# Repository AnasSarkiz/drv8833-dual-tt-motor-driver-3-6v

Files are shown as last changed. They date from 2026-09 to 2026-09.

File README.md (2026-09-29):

# DRV8833 dual TT motor driver, 3–6 V — routed prototype

[Public PCB](https://tscircuit.com/AnasSarkiz/drv8833-dual-tt-motor-driver-3-6v#pcb) · [GitHub repository](https://github.com/AnasSarkiz/drv8833-dual-tt-motor-driver-3-6v)

**Alpha.8:** the bottom silkscreen now reads “For evaluation only; not FCC approved for resale.” [Preview, fabrication artwork and checks](artifacts/silkscreen-review/README.md). Use the [updated fabrication ZIP](artifacts/silkscreen-review/jlc-fabrication-bottom-label.zip) for this label; the older alpha.6 order packet does not include it. [Publication status](PUBLICATION.md).

Revision A; package 0.1.0-alpha.8. **Routing is complete; physical qualification for fabrication and sale is still pending.** Native netlist and placement checks, full schema validation and fresh native routing checks pass. See [VALIDATION.md](VALIDATION.md) for evidence and remaining classified warnings.

Alpha.7 improves the four schematic sheets with nearby chip functions/ratings and connector labels. Electrical connections, PCB geometry and the alpha.6 prototype manufacturing packet are unchanged. [Schematic design review and previews](SCHEMATIC_REVIEW.md).

**Prototype order packet:** [Layout/export fixes completed; final quote and manufacturer preview remain](ORDER_READINESS.md). [Current stock for five boards](artifacts/order-release/STOCK.md).

A four-layer driver module for two brushed TT motors, controlled by an external host. The [reference TT motor](https://www.adafruit.com/product/3777) mounts to the chassis separately. This PCB is **75 × 60 × 1.6 mm**, with four **3.2 mm non-plated M3 holes on 65 × 50 mm centers** and 7 mm hardware keepouts. It is a generic module with a custom mounting pattern; compatibility with a particular chassis is not claimed. [Dimensioned mounting template](artifacts/routed/mounting-template.svg).

Minimum via drill **0.30 mm**, minimum via pad **0.45 mm**. The final board has 72 trace records, 60 through vias and ground pours on top, inner1 and bottom. Inner1 also carries signal routes. The four vias under U1 are thermal vias connected to ground, not mounting posts. [Routing details and layer previews](ROUTING_REVIEW.md).

The design has 47 purchased parts, 23 imported part types, five LEDs, seven bare test pads, separate A/B shunts and an NTC divider. The input target is **3–6 V at J1 including supply tolerance**. Nominal current chopping is about 1.33 A/channel; neither this nor the 1 A/channel continuous objective is a verified board rating. Hot-path voltage loss, regenerative spikes and thermal performance need bench testing. F1 is a non-resettable 3 A fuse; diagnose the fault before replacement. [Electrical review](DESIGN_REVIEW.md).

**SW1 — HOLD TO DISABLE:** hold the button to disable both motor outputs and let the motors coast. Release returns control to the host and can restart motion. It does not disconnect board power. [Button design and operating details](BUTTON_REVIEW.md).

## Connector pinout

All pin numbers are component pin numbers. Header geometry and assembly orientation remain under review.

| Connector | Pin 1 | Pin 2 | Pin 3 |
|---|---|---|---|
| J1 input | VIN | GND | — |
| J2 motor A | AOUT1 | AOUT2 | — |
| J3 motor B | BOUT1 | BOUT2 | — |
| J4 host power/enable | VIO input | GND | ENABLE / nSLEEP |
| J5 channel A | AIN1 | AIN2 | GND |
| J6 channel B | BIN1 | BIN2 | GND |
| J7 diagnostics | FAULT_N | TEMP | GND |

VIO is supplied by the host: match 3.3 V logic with 3.3 V VIO, or 5 V logic with 5 V VIO. It is not a power output. Mixed-voltage configurations are not approved. Pull-downs hold all commands and ENABLE low with disconnected high-impedance host pins. The host must drive ENABLE low before initialization, set commands to coast, then enable and wait at least 1 ms before PWM. Use command inputs for speed PWM, not nSLEEP. Both inputs low request coast, unequal inputs request drive, both high request brake; direction depends on motor wiring. All timing and sequencing require prototype confirmation.

LED1 indicates protected VM; LED2 VIO; LED3/4 unequal A/B commands (they can light while the driver sleeps); LED5 asserted fault. No LED measures rotation. TEMP measures local board temperature, not motor winding or silicon junction temperature. Its revised 56 kΩ/10 kΩ divider gives TEMP≈0.1515×VIO at 25°C; it is not an automatic cutoff. TP1/2 expose raw switching sense nodes, not calibrated ADC current telemetry. TP3 is GND; TP4 VM; TP5 VIO; TP6 FAULT_N; TP7 TEMP.

## Reproduce and inspect

Run `bun install --frozen-lockfile`, `bun run format:check`, `bun run typecheck`, `bun run build`, then `bun test`. `bun run render` regenerates the layer and schematic previews. Build validates the real generated output and checks physical routing; it does not patch Circuit JSON or suppress errors. The saved routes are editable native TSX route paths with validated component anchors.

Three unpublished, source-patched toolchain packages are included in `vendor/`, with exact upstream bases, regression tests and patches in [references/toolchain-fixes](references/toolchain-fixes/README.md). See [TOOLCHAIN.md](TOOLCHAIN.md).

- [BOM](BOM.md), [imports](IMPORTS.md), [placement](PLACEMENT_REVIEW.md) and [mechanical dimensions](MECHANICAL.md)
- [Validation](VALIDATION.md), [routing status](ROUTING_GATE.md) and [tool limitations](ISSUES.md)
- [Assembly review](ASSEMBLY_PLAN.md) and [physical test plan](TEST_PLAN.md)
- [Working reference comparison](REFERENCE_BOARD_REVIEW.md)
- [Public repository and registry receipts](PUBLICATION.md)

Earlier `artifacts/pre-route/` files are historical and are superseded by `artifacts/routed/`. No manufacturing order has been placed.

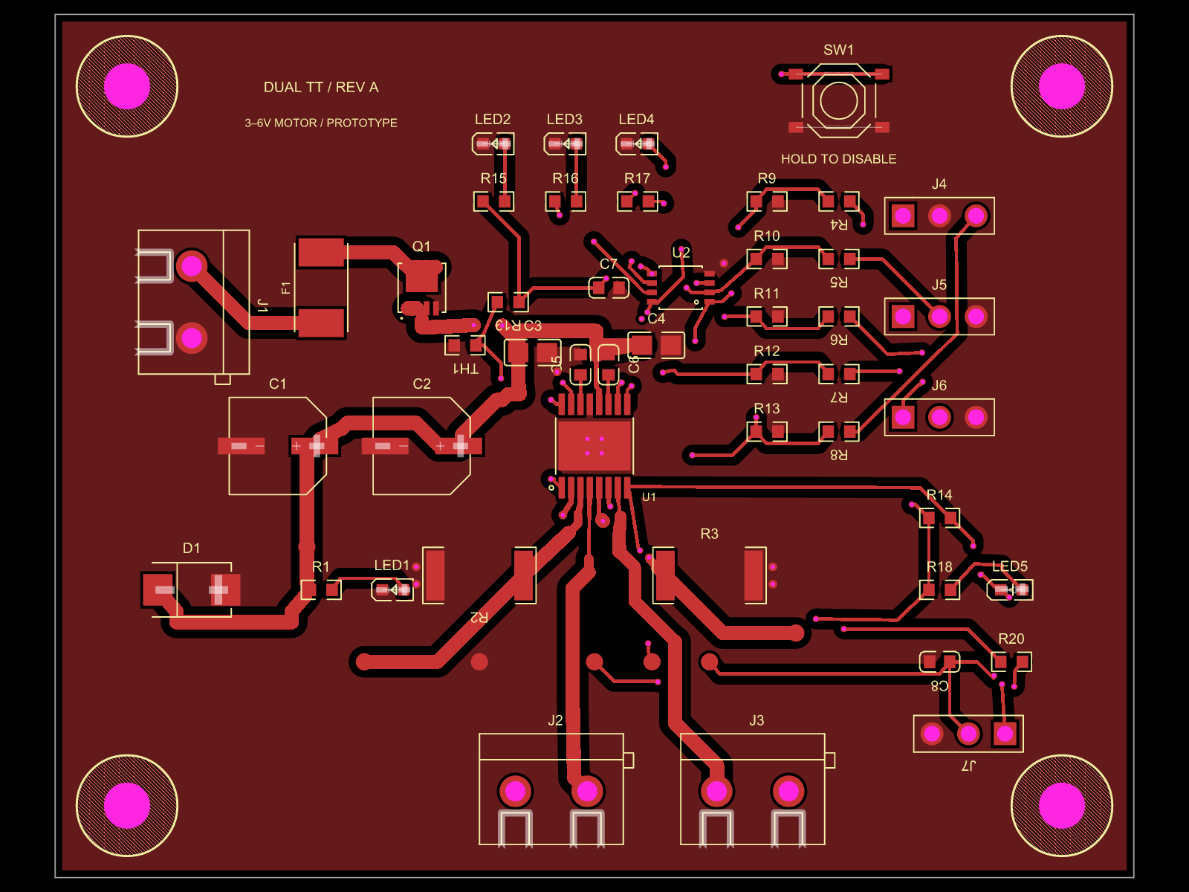
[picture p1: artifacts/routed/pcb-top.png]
Routed top layer


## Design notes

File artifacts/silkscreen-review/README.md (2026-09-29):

# Bottom evaluation label — alpha.8

The bottom silkscreen reads:

> For evaluation only;  
> not FCC approved for resale.

Both lines use 1.8 mm lettering, centered at (0, 25) mm and (0, 22.5) mm. The exported stroke width is 0.162 mm. Visual inspection confirms clearance from through-hole pads, vias and mounting hardware zones. Bottom text is mirrored in the top-down layer drawing so it reads correctly when the physical board is viewed from underneath.

- [Bottom layer preview](../routed/pcb-bottom.png)
- [Fabrication artwork ZIP with the label](jlc-fabrication-bottom-label.zip)
- [Native combined export](dual-tt-bottom-label-gerbers.zip)
- [Artwork comparison and generated label records](verification.json)

Netlist: zero errors/warnings. Placement DRC: zero errors/warnings; the existing C7 orientation advisory remains. Format, TypeScript, build, schema, mechanical and physical-connectivity checks pass. All 27 existing tests / 1,139 assertions pass. No new tests or check exemptions were added for this silkscreen-only change.

All non-silkscreen PCB records and electrical connectivity records are identical to the previous build. After ignoring export timestamps and resolving aperture-number renumbering, comparison against the alpha.6 manufacturing artwork finds exactly one changed file: `B_SilkScreen.gbr`. Copper, drills, outline, top silkscreen, solder mask and paste are unchanged.

The fabrication ZIP contains only native Gerber/drill files. J1–J7 still require manual assembly; retain the existing separate SMT assembly files and manufacturing notes. The native combined export's all-component pick-and-place file still has the documented J4–J7 orientation warnings.

See [publication status](../../PUBLICATION.md) for GitHub and tscircuit verification. The older alpha.6 order packet remains a historical export without the new label. No stock refresh, production order or regulatory approval is implied.

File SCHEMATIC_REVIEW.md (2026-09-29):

# Schematic design review — alpha.7

Reviewed 29 September 2026. The four sheets now include native `<schematictext>` notes beside every chip: U1, U2 and the chip-style Q1 symbol. Labels also identify all connectors, the disable button and the temperature measurement.

| Part | Nearby explanation |
|---|---|
| U1 DRV8833 | Two brushed-DC motor bridges; IC VM range 2.7–10.8 V, board input target 3–6 V, nominal 1.33 A/channel current chopping; continuous current requires thermal testing |
| U2 SN74LVC2G86 | Dual XOR for command LEDs; IC VCC range 1.65–5.5 V, board VIO 3.3/5 V; indication measures commands rather than rotation |
| Q1 SI7655ADN | P-channel reverse-polarity protection, −20 V VDS rating and source/drain/exposed-pad connections |

Ratings were checked against the [TI DRV8833 datasheet](https://www.ti.com/lit/ds/symlink/drv8833.pdf), [TI SN74LVC2G86 datasheet](https://www.ti.com/lit/ds/symlink/sn74lvc2g86.pdf) and [Vishay SI7655ADN datasheet](https://www.vishay.com/docs/62909/si7655adn.pdf). IC limits are distinct from the board's intended supply and unqualified continuous-current target.

Host headers and input networks use separate schematic sections to replace obstructing ground wires with labeled connections. Diagnostic test pads are likewise separated from J7. Notes have consistent font size and line spacing, remain inside their sheets and were visually checked against wires, symbols and labels in all four regenerated previews. Native schematic-placement checks report no collision or overlap findings. Remaining box-padding and orientation suggestions are non-blocking style heuristics, retained without suppression.

The build, full schema guard, native netlist, mechanical checks and native routing checks pass. Placement DRC reports zero errors and warnings, with the existing advisory C7 orientation suggestion. All 27 board tests pass with the same 1,139 assertions; the independent drill and pad rejection cases now run separately, each retaining the default runner deadline and full validation.

All 1,000 PCB records, 54 CAD records and electrical component/port/net/trace records exactly match alpha.6. Every file in the alpha.6 order-release directory is unchanged. [Comparison evidence](artifacts/schematic-review/unchanged-hardware.json) and [check logs](artifacts/schematic-review/logs/). The schematic update adds no hardware or manufacturing qualification.

## Rendered sheets

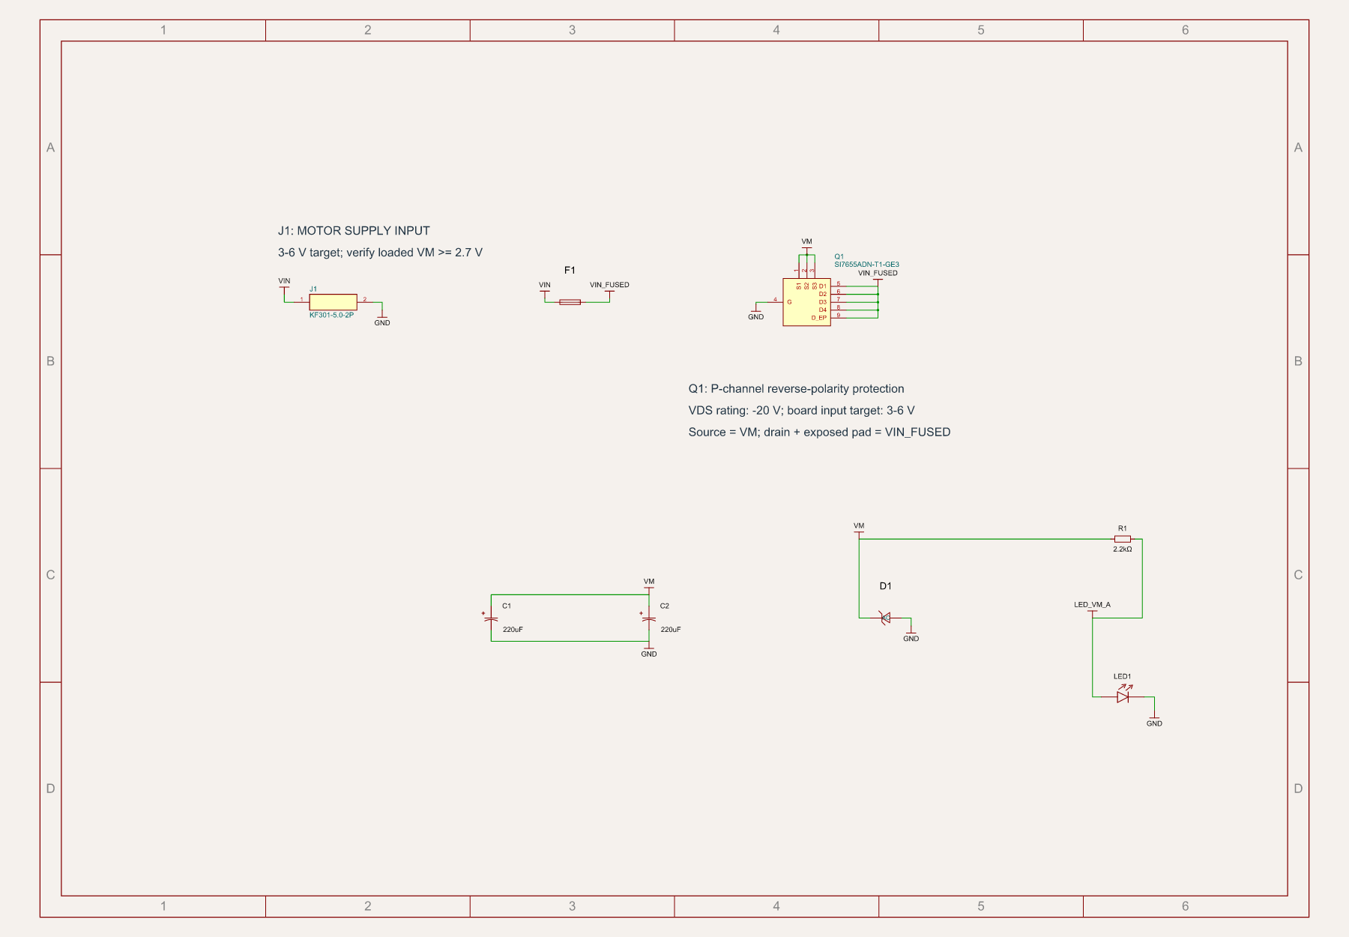
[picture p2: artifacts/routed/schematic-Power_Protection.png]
Power and protection


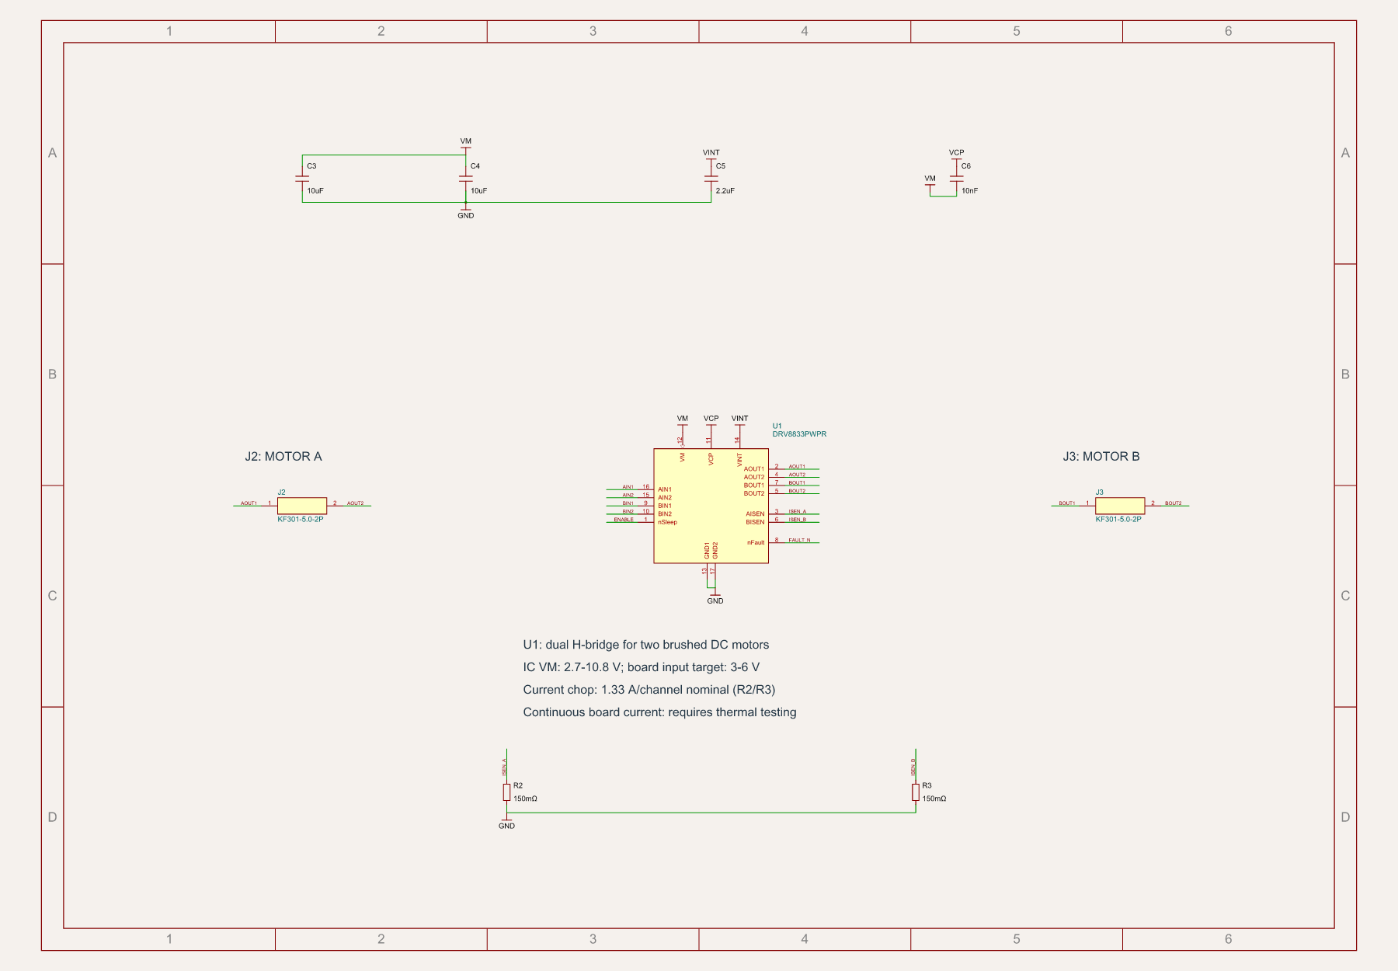
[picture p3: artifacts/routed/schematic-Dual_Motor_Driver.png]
Dual motor driver


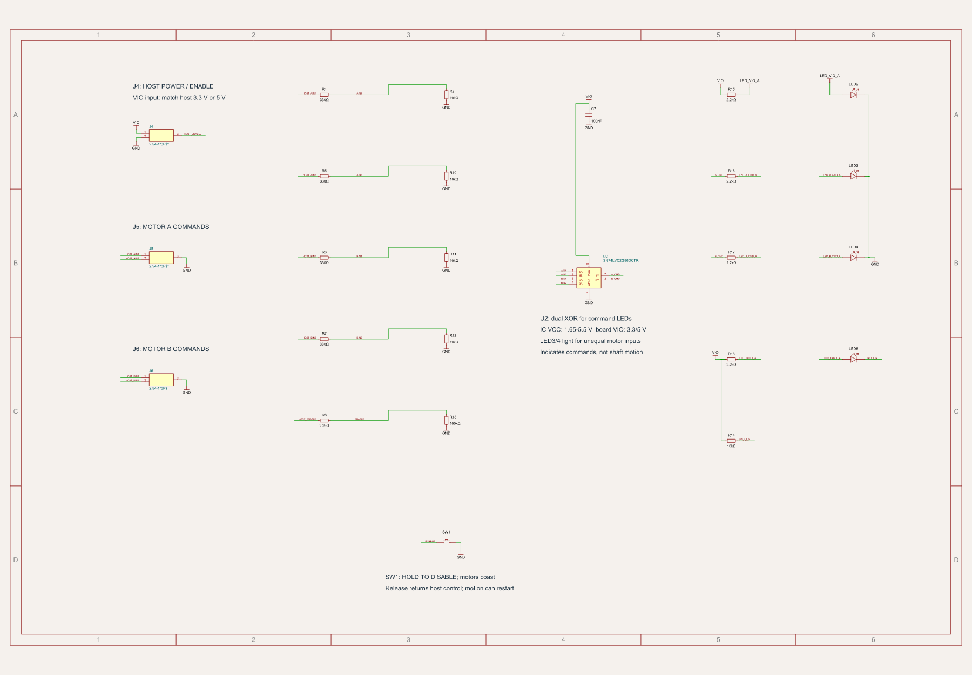
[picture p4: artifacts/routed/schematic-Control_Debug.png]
Control and debug


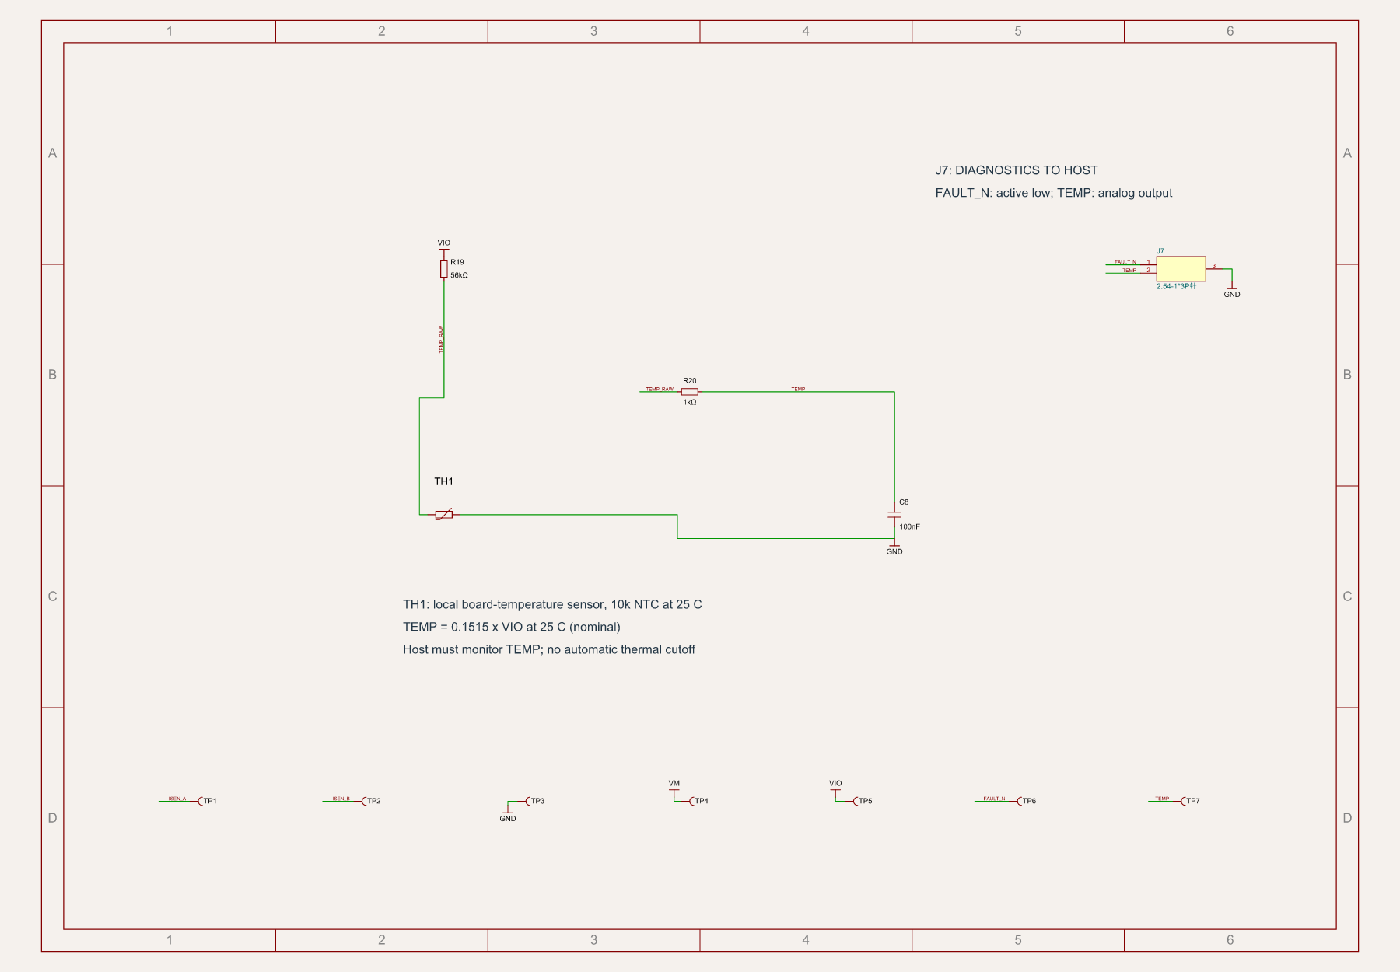
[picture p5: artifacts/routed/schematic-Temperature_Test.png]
Temperature and test access


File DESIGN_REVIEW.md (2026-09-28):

# Electrical design review — incomplete

Analysis only; no physical measurements or circuit simulation. This file records both calculations and blocking decisions. The alpha.3 prototype is now routed and passes automated routing checks. The physical rating and manufacturing qualification items below remain open; routing does not resolve them.

## Power architecture

J1 VIN → F1 fuse → Q1 drain, Q1 source → VM. The P-channel gate is at GND; its body diode starts the protected rail in the correct direction. VM feeds U1, two bulk capacitors, local ceramic bypass, the TVS candidate and VM LED. This arrangement does not block returned regenerative current when Q1 is on. U1 GND and exposed pad are separate from the AISEN/BISEN nodes, which each connect to GND only through their own 0.15 ohm shunt.

The store-product target remains **3.0–6.0 V at J1, including supply tolerance**, for two small TT motors. The user's adjustable regulated supply is test equipment, not a restriction on the product. Battery packs and regulated adapters must be assessed by their actual voltage range and ability to accept returned motor energy. Nominal pack labels alone do not establish compatibility; no specific battery pack, USB source or adapter is approved yet.

Q1 is now Vishay **Si7655ADN-T1-GE3, C222495**. Its 9 mΩ maximum at VGS=-2.5 V and 25°C replaces AO3401A's 85 mΩ. Its gate limit is ±12 V and drain rating 20 V. Physical pins 1/2/3 are source (VM), 4 gate (GND), 5/6/7/8 drain (VIN_FUSED); imported pad 9 is the same exposed drain metal. The datasheet bottom view was visually checked. The exact imported land pattern and assembly process still need completion. [Vishay datasheet](https://www.vishay.com/docs/62909/si7655adn.pdf).

F1 is now Littelfuse **0453003.MR, C178991**, a **non-resettable 3 A fuse**. This replaces the PTC; a blown fuse requires fault diagnosis and replacement. Its nominal cold resistance is 22.7 mΩ, not a guaranteed hot maximum. At 25°C use the manufacturer's 75% continuous-current derating: 2.25 A; ambient rerating applies additionally. This is input fault protection, not the per-channel motor limiter. The datasheet allows up to 5 s opening at twice rated current, so it does not guarantee semiconductor survival during every fault. Source fault current and fuse/TVS coordination remain to be closed. [Littelfuse 451/453 datasheet](https://www.littelfuse.com/assetdocs/fuse-451-and-453-datasheet?assetguid=533cd5cc-956c-4243-867f-6ab5a62f6ba1).

At 2 A shared input, Q1 plus F1 contribute approximately 2×(0.009+0.0227)=**0.0634 V** and 0.127 W, versus the prior optimistic 0.29 V. This combines a room-temperature MOSFET maximum with a fuse nominal: it is an estimate, not a system guarantee. A provisional hot-path design budget of Q1≤20 mΩ, F1≤50 mΩ and contacts/copper≤30 mΩ totals 0.20 V at 2 A, leaving VM≥2.8 V for 3.0 V measured at J1. These are acceptance targets to verify, not manufacturer-guaranteed bounds. Supply sag must not pull J1 below 3 V. Reliable simultaneous starts at minimum input remain unverified.

D1 is now **Littelfuse SMBJ6.0A, C83270**, replacing the unverified MSKSEMI candidate. The manufacturer series sheet specifies 6.0 V standoff, 6.67–7.37 V breakdown at 10 mA, and 10.3 V maximum clamp at 58.3 A for its stated pulse condition. Reverse leakage is up to **800 µA**, not the supplier-description number. The 0.046%/°C column is a breakdown temperature coefficient. Do not treat 600 W pulse capability as continuous braking power or scale the clamp by the breakdown coefficient and call it guaranteed. The 10.3 V value leaves only 1.5 V to U1's 11.8 V absolute limit; hot clamping, wiring/layout overshoot and repetitive energy must be budgeted. [Manufacturer SMBJ series sheet, supplier-hosted](https://datasheet.lcsc.com/datasheet/pdf/4ab84a227fae39f9eac85241b8264ead.pdf).

Two 220 µF capacitors give 440 µF nominal and 352 µF at -20%. Ignoring losses, returned energy of 1 mJ from 6 V raises VM to 6.46 V; 10 mJ raises it to 9.64 V. These are examples, not measured TT-motor energies. Required braking/reversal energy, pulse repetition, bulk ESR/ripple/lifetime and transient clamp temperature remain open. **The regenerative-energy solution is not approved.** Q1 conducts returned current when on; it is not a reverse-current blocker. Do not assume a bench supply or power bank can absorb this energy.

## Driver pin audit

Compared with [TI DRV8833 PWP pin table](https://www.ti.com/lit/ds/symlink/drv8833.pdf):

| Pad | Imported signal | Intended net |
|---|---|---|
| 1 | nSleep | ENABLE |
| 2 | AOUT1 | AOUT1 |
| 3 | AISEN | ISEN_A |
| 4 | AOUT2 | AOUT2 |
| 5 | BOUT2 | BOUT2 |
| 6 | BISEN | ISEN_B |
| 7 | BOUT1 | BOUT1 |
| 8 | nFault | FAULT_N |
| 9 | BIN1 | BIN1 |
| 10 | BIN2 | BIN2 |
| 11 | VCP | VCP |
| 12 | VM | VM |
| 13 | GND1 | GND |
| 14 | VINT | VINT |
| 15 | AIN2 | AIN2 |
| 16 | AIN1 | AIN1 |
| 17 | GND2 / exposed pad | GND |

C6 is VCP-to-VM, not VCP-to-GND. C5 bypasses VINT, with no external VINT load. C3/C4 provide 20 uF nominal VM ceramic capacitance; exact DC-bias/temperature curves must establish the effective minimum. Driver PWM strategy, fault recovery and wake timing still need a consolidated worst-case review.

## Current limit and thermal targets

The [TI DRV8833 datasheet](https://www.ti.com/lit/ds/symlink/drv8833.pdf) specifies a 160/200/240 mV current-trip threshold at the table's stated conditions. With 0.15 Ω ±1%, the calculated range is **1.056–1.616 A** at those conditions; nominal 1.333 A. Including a ±600 ppm/°C shunt TCR over a 75°C change expands the resistor scenario to **1.011–1.692 A**. That is not a guaranteed all-temperature IC limit. Switching blanking and motor inductance can permit additional overshoot. Nominal shunt dissipation is 0.267 W; the upper resistor/threshold scenario is about 0.406 W. Shunt pulse/derating and a lower-TCR alternative remain under review.

At the datasheet's 85°C, 5 V resistance condition, a bridge's combined maximum on-resistance is 0.600 Ω: two channels at 1 A imply about 1.2 W conduction loss. At the 2.7 V condition the estimate is 1.3 W. These extrapolations exclude switching and other losses. An engineering junction target of 125°C at 40°C ambient and 1.3 W requires effective thermal resistance below 65°C/W before those extra losses. The datasheet fixture is not this board. Copper spreading, filled thermal vias, enclosure airflow and actual motor duty need verification. **1 A/channel continuous remains a target, not a product rating.** FAULT_N is not a stall detector; the host needs a blocked-motor timeout.

## Host interface and indicators

R4–R7 use **330 Ω ±1% C23138** and 10 kΩ pull-downs. Commands allowing 33 µA driver plus 5 µA XOR leakage give approximately 2.697 V at host VOH=2.8 V. Alpha.6 uses **R8=2.2 kΩ C4190 / R13=100 kΩ C25803** for ENABLE, giving at least 2.710 V with the stated 13 µA input current and worst resistor tolerances. SW1 pulls ENABLE low while held; R8 limits pressed host current to 2.411 mA at 5.25 V. Require a GPIO that can source at least 2.5 mA. These calculations use datasheet input-current test conditions; they are not a universal host guarantee. For a 5 V host, require matching VIO and verify loaded VOH against U2's 0.7×VIO requirement; a 4.4 V host-high target provides useful margin at VIO≤5.25 V. Input edge rate and loading still need oscilloscope qualification. See [button review](BUTTON_REVIEW.md) for contact topology and restart behavior.

Use VIO from the same host rail: 3.3 V or 5 V, with no arbitrary mixed-voltage modes. The [SN74LVC2G86](https://www.ti.com/lit/ds/symlink/sn74lvc2g86.pdf) allows inputs to 5.5 V and supports partial power-down; its input edge-rate limits still apply. Series resistance is not a complete connector ESD solution.

Worst preliminary FAULT loading at 5.25 V is about 2.11 mA from LED5 and its 10 kΩ pull-up, leaving margin below the 5 mA characterized sink condition. Limit additional external loading and verify host low threshold against 0.5 V. LED1 indicates VM, LED2 VIO, LED3/4 unequal channel commands, LED5 asserted fault. Command LEDs can light while asleep; none measures rotation.

## Temperature interface correction

The [Murata NCP18XH103F03RB specification](https://www.murata.com/products/productdetail?partno=NCP18XH103F03RB) lists 0.1 mA maximum measuring current at 25°C. The original equal-10 kΩ divider exceeded this. **R19 is now 56 kΩ ±1% C23206.** Even at VIO=5.25 V and R19=-1%, divider current stays below 94.7 µA as NTC resistance approaches zero. At 25°C nominal TEMP/VIO is 10/(56+10)=0.151515: 0.500 V at 3.3 V or 0.758 V at 5 V. Estimated self-heating at the upper rail is about 0.065°C using the typical dissipation constant; the actual board environment changes it.

Use R_NTC=56000×TEMP/(VIO−TEMP), assuming negligible ADC loading and a ratiometric reference. TEMP is a raw board-temperature signal, not an automatic cutoff or motor/junction reading. The full manufacturer R/T table and final accuracy budget remain open; the 25/50 beta value must not be used as a guaranteed full-range conversion.

R20=1 kΩ and C8=100 nF give roughly 0.95 ms at 25°C and a nominal cold limit of 5.7 ms. Allow at least 35 ms initial settling, subject to capacitor tolerance. The host must use a high-impedance ADC and suitable acquisition time; its input must accept the complete 0–VIO range. Open/short sensor readings approach rail endpoints and require host fault handling.

## Power states and motor commands

TI explicitly allows digital inputs before VM. U2 supports powered-off inputs within its specified range. This resolves the earlier blanket prohibition on host-first power-up; it does not authorize every hot-plug or backfeed configuration.

| VM | Host VIO | Host commands | Design behavior / condition |
|---|---|---|---|
| absent | absent | high impedance | No driven motor operation |
| present | absent | high impedance | External pulls request sleep/coast; leakage/default state requires prototype confirmation |
| absent | present | valid 0–VIO levels | Host-first sequencing allowed by the IC specifications; keep ENABLE low |
| present | present | ENABLE low | Sleep requested |
| present | present | ENABLE high | Wait at least 1 ms after waking; set motor commands deliberately |
| returns after interruption | present | ENABLE already high | Motor may restart immediately; host must handle supply recovery and hold sleep during initialization |
| either | VIO powered independently of an unpowered host | FAULT/TEMP connected | Unsupported: those outputs can backfeed the host |
| either | changing | hot plug / long leads | Connector bounce, transients and ESD not qualified |

Drive PWM on the command inputs, not nSLEEP. Both low request coast, unequal inputs drive, both high request brake. A brake command and rapid reversal require the unresolved energy review above. Before initialization or mode changes, deassert ENABLE and choose a controlled restart sequence. VIO is an input, never a board power output.

## Remaining pre-routing decisions

Close the bus-energy budget and fault-source assumptions, capacitor bias/ripple review, shunt pulse/TCR choice, exact footprints and assembly process, connector access in 3D, and external-port ESD/interface limits. Software schema defects are tracked separately in ISSUES.md. All physical tests remain NOT RUN. The generic 75 × 60 mm chassis module and mounting pattern are accepted; no specific chassis is required to continue. MCU, crystal, USB, firmware flashing, radio, charger and encoder are NOT APPLICABLE to this external-controller design.

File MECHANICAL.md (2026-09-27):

# Chassis mounting — revision A prototype

The user selected a standalone chassis-mounted module and has not selected a chassis. The PCB uses ordinary M3 hardware with a **custom 65 × 50 mm rectangular hole pattern**. This is a practical module size, not a standardized pattern or a claim of direct fit to every TT chassis. Motors attach to their chassis or brackets separately; short wires connect them to J2/J3.

| Feature | Design dimension |
|---|---|
| PCB outline | 75 × 60 mm |
| Thickness / stack | 1.6 mm / four layers |
| Mounting holes | Four 3.2 mm non-plated holes, for M3 screws |
| Hole centers | 65 × 50 mm; each center 5 mm from two adjacent edges |
| Coordinates about board center | H1 (−32.5, +25), H2 (+32.5, +25), H3 (−32.5, −25), H4 (+32.5, −25) mm |
| Hardware reserve | 7 mm diameter at every hole, copper keepout on all four layers |
| Proposed spacers | Four M3 insulating standoffs, 10 mm tall; check actual solder-tail clearance |
| Via minima | 0.30 mm drill / 0.45 mm copper pad; these are unrelated to mounting-hole size |

[Mounting template](artifacts/routed/mounting-template.svg) is drawn in physical millimeters. Print at 100% and check the 50 mm scale with a ruler. It is a mechanical review aid, not a PCB fabrication package. The canonical dimensions are in `references/mechanical.json`; source holes, keepouts and template use that file.

Use a flat chassis deck or adapter that accepts this hole rectangle, with room beyond the board for wiring. Do not drill a purchased chassis until you check its motor, wheel, battery and structural clearances. Use insulating standoffs over metal; washers and screw heads must fit within the reserved 7 mm diameter. Clearance to connector housings, mated plugs, wire bends and the screwdriver requires a physical or verified 3D check. Vertical headers need access from above; screw terminals also need top tool access. Fastener lengths depend on the actual chassis thickness and standoff thread depth and are not selected yet.

The real generated output is checked for board size, all four holes/keepouts and all 53 component/test-pad courtyard envelopes by `scripts/check-mechanical.ts`. Each component courtyard must clear every hardware reserve by at least 0.5 mm. Both this geometric check and full Circuit JSON schema validation pass for the routed prototype.

Research supports the mounting arrangement: [Adafruit's TT chassis](https://www.adafruit.com/product/3796) places the TT motors on its side walls and provides holes/slots for controller boards on the deck. Its [dimension drawing](https://cdn-shop.adafruit.com/product-files/3796/3796_diagram_2.jpg) does not define a universal controller-board pattern. That discontinued chassis was used as a reference only; this PCB is not advertised as matching its existing holes. Actual chassis fit and enclosure heights remain unverified until a chassis is selected.

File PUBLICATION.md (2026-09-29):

# Public routed release

## Alpha.8 — bottom evaluation label

**Alpha.8 is published to both public repositories.** The bottom silkscreen now reads “For evaluation only; not FCC approved for resale.” [Bottom preview and updated fabrication ZIP](artifacts/silkscreen-review/README.md).

| Destination | Verified result |
|---|---|
| GitHub source | `d1f7bbf01a7ee00ec65604b4830edd94331d7d5b` pushed to `main` |
| [GitHub CI](https://github.com/AnasSarkiz/drv8833-dual-tt-motor-driver-3-6v/actions/runs/36605200165) | PASS: frozen install, format, TypeScript, build and 27 tests / 1,139 assertions |
| [tscircuit PCB](https://tscircuit.com/AnasSarkiz/drv8833-dual-tt-motor-driver-3-6v#pcb) | Latest release `0.1.0-alpha.8-routed`; release ID `20e4c3da-a9a2-4ae0-bc2e-cdc5a9c807a3` |
| Upload verification | 388 files uploaded; all 256 non-dotfile source/toolchain/review hashes match |
| Cloud build | Completed successfully; 1,921 schema-valid records, zero error records and zero native routing findings |
| Cloud comparison | All 1,002 PCB, 468 schematic and 54 CAD records exactly match local output; electrical connections also match |
| Bottom label | Both lines present on `bottom`, with 1.8 mm font size |

[Machine-readable publication receipt](artifacts/silkscreen-review/publication.json). Only bottom silkscreen artwork changes relative to the alpha.6 manufacturing export after normalizing timestamps and aperture numbers. Copper, drills, mask, paste and top silkscreen are unchanged. The older alpha.6 order packet does not contain the new label; use the separate updated fabrication ZIP linked above.

The registry's aggregate display status remains `pending` despite successful completion of its custom build and verified generated output. This GitHub-only receipt records the results; the registry snapshot contains the preceding publication-status document. The online editor's separate saved-routing issue remains tracked in [tscircuit/core#4197](https://github.com/tscircuit/core/issues/4197); this silkscreen update does not resolve it.

## Alpha.7 — schematic review receipt

Both repositories are public. **Alpha.7 adds the reviewed schematic notes and labels and passes local, GitHub CI and tscircuit cloud checks.** Its PCB, electrical connections and alpha.6 prototype manufacturing packet are unchanged.

| Destination | Verified result |
|---|---|
| [GitHub](https://github.com/AnasSarkiz/drv8833-dual-tt-motor-driver-3-6v) | Public; alpha.7 source, previews and review evidence pushed |
| [GitHub CI](https://github.com/AnasSarkiz/drv8833-dual-tt-motor-driver-3-6v/actions/runs/36557758551) | PASS: frozen install, format, TypeScript, build and all 27 tests / 1,139 assertions |
| [tscircuit schematic](https://tscircuit.com/AnasSarkiz/drv8833-dual-tt-motor-driver-3-6v#schematic) | Public; latest release `0.1.0-alpha.7-routed`; new notes confirmed in the live viewer |
| Release ID | `9af54a06-8175-491e-a563-65f439ab72b8` |
| Published source commit | `74fee42fa5bdbf5f3e427e5dbdb20cfa620682b3` |
| Upload verification | 377 files uploaded; all 246 non-dotfile source, toolchain, manufacturing and review hashes match through the public API |
| Cloud build | Completed without error; all 1,919 records pass schema and routing-contract validation; native routing checks: 0 findings |
| Cloud comparison | All 1,000 PCB records and 468 schematic records exactly match local output, including all 26 new note lines |
| Manufacturing comparison | All 53 alpha.6 order-release files remain byte-identical |

See [schematic review](SCHEMATIC_REVIEW.md) for the four rendered sheets and chip-rating sources. The PCB still has 72 traces, 60 vias, four pour polygons, 110 top paste apertures and no bottom paste. Notes identify U1, U2, Q1, connectors, the disable button and temperature measurement without changing physical circuitry.

The local output includes 47 supplier-lookup network warnings that are absent from the cloud output. These report inability to connect, not missing imported footprints; all PCB, CAD, electrical and schematic records match exactly. The only other local/cloud difference is the source filesystem metadata hash. Native placement and symbol style advisories remain documented without suppression. Registry aggregate display status remains pending and its separate thumbnail URL is absent despite successful code generation and the functioning schematic viewer.

The 247-entry manifest includes one dot-prefixed GitHub workflow excluded by registry upload rules. All other hashes match. The registry snapshot contains the preceding publication receipt; this later GitHub-only receipt and [publication.json](artifacts/routed/publication.json) record alpha.7's remote results. Publication receipts and their upload/CI logs are excluded from the manifest.

The unchanged [prototype order packet](artifacts/order-release/dual-tt-prototype-order-packet.zip) remains subject to [order readiness](ORDER_READINESS.md), final manufacturer review and stock reservation. The stock evidence is dated 28 September 2026 and was not refreshed for this schematic-only revision. Physical motor, supply-spike, button and thermal tests remain necessary before a store release. No order has been placed.

The repositories are published separately. Automatic linking previously returned `403 repository_not_accessible` from the tscircuit GitHub app; no broader app permissions were granted.

## Repository rename

On 2026-09-28, both repositories were renamed to `drv8833-dual-tt-motor-driver-3-6v`. Existing public visibility, repository/package IDs, history and previous releases were preserved.

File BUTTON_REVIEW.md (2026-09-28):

# Motor-disable button — alpha.6

SW1 is a normally-open momentary tactile button, labeled **HOLD TO DISABLE**. Holding it pulls the DRV8833 ENABLE/nSLEEP input low and disables both H-bridges. Motors coast; the board remains powered. Releasing it returns control to the external host and can restart the motors after the driver's wake delay. This is a local operating control, not a latching stop, active brake, power disconnect or emergency-stop circuit. No new firmware is required for its basic function.

Comparable DRV8833 carriers expose sleep/enable control, as in the [Adafruit pinout guide](https://learn.adafruit.com/adafruit-drv8833-dc-stepper-motor-driver-breakout-board/pinouts) and [Pololu carrier](https://www.pololu.com/product/2130). A button is an optional convenience; these references do not establish a universal button convention. The chosen momentary disable function uses the [TI nSLEEP behavior](https://www.ti.com/lit/ds/symlink/drv8833.pdf), sections 7.3.4 and 7.4.

## Electrical and mechanical review

- **SW1: XKB TS-1187A-B-A-B, JLC C318884**, Basic, top SMT, 5.1 × 5.1 × 1.5 mm body; 50 mA / 12 V DC contact rating. The [manufacturer drawing](references/TS-1187A-B-A-B.pdf) was visually reviewed. A–B (pins 1–2) and C–D (pins 3–4) are permanent pairs; pressing connects the two pairs. A/B connect to ENABLE, C/D to GND. The native pushbutton model explicitly includes these pairs.
- The supplier footprint has 1.00 × 0.75 mm pads at X=±3.00 mm, Y=±1.849882 mm. The drawing's suggested land pattern gives X=±3.00 mm, Y=±1.875 mm; the 0.025118 mm Y difference is inside its general ±0.1 mm tolerance. The imported body courtyard is retained. Parts-engine pin-1 matching verifies the supplied CPL orientation; the final assembly preview must confirm the contact-row axis, since a 90° error would bridge ENABLE to ground.
- **R8 changes from 330 Ω to 2.2 kΩ (C4190)**. With a 5.25 V host and −1% resistance, pressing draws at most 2.411 mA from HOST_ENABLE and dissipates about 12.66 mW in R8 (100 mW part). Require a host GPIO that tolerates this source current. At the switch's specified 100 mΩ maximum contact resistance, ENABLE is below 0.25 mV, well under the 0.5 V input-low limit.
- **R13 changes from 10 kΩ to 100 kΩ (C25803)**. At host VOH=2.8 V, R8=+1%, R13=−1%, and the datasheet's stated 13 µA nSLEEP current, ENABLE is at least 2.710 V, above the 2.5 V threshold. This is a calculation at the specified input-current conditions, not a universal host guarantee. R13 and the driver's internal pull-down retain the disconnected-host sleep default. The four motor-command inputs retain 330 Ω / 10 kΩ networks.
- SW1 center is (17,24) mm on top, away from the corner mounting keepout and host connectors. Its two added ENABLE paths use 0.25 mm copper and two 0.30/0.45 mm vias. All previous saved power and signal paths remain unchanged. Ground contacts join the checked top pour. Four-layer, 75 × 60 mm board size and mounting pattern are unchanged.

## Verification and use

Native netlist and placement DRC: zero errors/warnings. Full schema, build, mechanical and native routing checks pass. The existing advisory C7 rotation suggestion remains. All 26 board tests / 1,139 assertions pass, including released/pressed switch contact topology, GPIO current budget, enable-high margin, ground continuity and strict supplier orientation. All four copper layers and the control schematic were visually inspected. Gerber-mode shorts at 40 px/mm reports no shorts. Final exports contain 40 top SMT placements, seven manual connectors, 110 top stencil apertures and no bottom paste.

Bench checks: with motors initially disconnected, measure ENABLE released/pressed at both supported host voltages; verify the host can source the pressed current. Test with wheels lifted: hold SW1 to remove drive, then confirm expected restart behavior on release. Verify wake timing, contact bounce and supply transients before normal operation. Use the external controller or a separate suitable power disconnect when a maintained stop is required. The existing motor/load/thermal test plan still applies.

Import and validation evidence: [button review artifacts](artifacts/button-review). Fresh component quantities: [five-board stock check](artifacts/order-release/STOCK.md). The final manufacturer preview, inventory reservation and physical tests remain separate.

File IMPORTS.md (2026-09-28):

# Import audit

23 selected part types imported with `tsci import C-number --jlcpcb --use-exact-footprint`. No fabricated packages. Original generated modules remain unchanged. The initial imports have logs in `artifacts/pre-route/import-results.json`; revision imports have separate logs in `artifacts/pre-route/logs/`. Unused original imports are retained for provenance and are not BOM rows. The original import hashes remain in `artifacts/pre-route/import-hashes.json`; the current imports are included in `artifacts/routed/hashes.json`.

An import is not an independent geometry review. DRV8833 pin labels match the PWP table. The design uses the TI-derived land pattern in lib/driver-footprint.tsx; see U1_FOOTPRINT.md. Its four ground thermal vias are listed in `references/thermal-structures.json`, including exact positions and sizes. The routed revision adds signal/power and ground-stitching vias; see ROUTING_REVIEW.md. Raw import geometry is unchanged.

Raw non-IC imports use generic chips. lib/parts.tsx supplies native electrical kinds, explicit connector entry directions and reference text while preserving the raw import files. U1 and F1 use separately reviewed manufacturer-derived footprints; see U1_FOOTPRINT.md and ASSEMBLY_PLAN.md. D1 was re-imported as Littelfuse C83270; R4–R7 use C23138 and R19 uses C23206. Q1 now uses Vishay C222495 and F1 uses non-resettable Littelfuse C178991. Import logs are retained. See ISSUES.md.

Alpha.6 adds C318884 (native pushbutton) and C25803 (100 kΩ resistor), imported with the same exact-footprint command. R8 reuses C4190 (2.2 kΩ). Raw imports remain unchanged; button contact pairs are declared by the board circuit using the reviewed manufacturer drawing. New logs and identity records are in `artifacts/button-review/`.

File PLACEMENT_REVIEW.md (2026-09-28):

# Placement review — routed prototype

The outline is 75 × 60 × 1.6 mm with four copper layers. Four 3.2 mm NPTH holes form a 65 × 50 mm rectangle, with 7 mm hardware keepouts on all layers. This is the accepted generic chassis-module arrangement, not a specific chassis fit claim.

All 47 purchased components are on top, together with seven bare test pads. There are 54 checked courtyards and 64 PCB-component records (including ten explicitly authored thermal/ground vias). Native placement DRC reports zero errors and warnings; the CLI’s separate C7 orientation suggestion is advisory. Every courtyard is inside the outline and clears each hardware reserve by at least 0.5 mm; J7 is the closest at 0.732 mm beyond the hardware zone. See `artifacts/order-release/logs/build.log`.

J1 faces the left edge; motor connectors J2/J3 face the bottom. The shunts are adjacent to the driver, with nearby ground stitches. C3/C4 and the sense/VM test-pad positions were adjusted to permit clean routing. U2's 2D courtyard is clear. Four layer previews are in `artifacts/routed/`.

The four U1 holes are conductive thermal vias, not mounting posts. Their 0.3048 mm drills / 0.6096 mm pads exceed the requested minima and now connect to GND copper. Six further ground stitches support the shunts, C3 and logic ground; all routes and pours are checked together for physical continuity.

Connector mating envelopes, tool access, standoff height, imported 3D model alignment and physical chassis fit remain unverified. Routing and 2D checks do not establish thermal performance or assembly readiness. See ASSEMBLY_PLAN.md and TEST_PLAN.md.

Alpha.5 capacitor positions: C3 (−4.3, 6.5), C4 (4.3, 7), C5 (−0.975, 5.65), C6 (0.975, 5.65) mm. C5/C6 rotate 90°. Both small-capacitor pin routes are now 2.05 mm without vias. All affected routes and courtyards were rechecked.

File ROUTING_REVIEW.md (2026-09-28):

# Routed revision A review

Routing is complete and passes fresh native routing checks with zero findings. All 32 non-GND nets use 71 saved reviewed native route paths; a short C3 ground connection makes 72 trace records. GND continuity is established through the checked ground pours, thermal vias and six added stitches.

The saved routes in `lib/saved-routing.ts` are canonical, editable route paths referenced by real component pin selectors. They originated from native capacity-autorouter 0.0.938, pipeline9, with additional routing margins. Alpha.5 locally revises U1 current return, bypass placement and affected neighboring paths. Alpha.6 adds two ENABLE route paths and two vias for SW1; the prior 69 saved paths are unchanged. They are consumed by the supported `autoroutingphase` API, which checks anchors, physical layers and endpoint coverage. Moving a component requires updating its affected saved paths. No Circuit JSON is injected or repaired after generation.

| Copper feature | Final geometry |
|---|---|
| Stack | Four layers, 1.6 mm board |
| Ground copper | Top (two polygons), inner1 and bottom (one polygon each) |
| Inner1 | Ground pour with some signal routes; not an exclusive or uninterrupted plane |
| Signal/power vias | 50 total: 49 at 0.30/0.45 mm; AOUT1 transition at 0.30/0.60 mm |
| Added ground stitches | Six, drill 0.30 mm / pad 0.60 mm |
| Original U1 thermal vias | Four, drill 0.3048 mm / pad 0.6096 mm |
| Board minimum via rule | Drill 0.30 mm / pad 0.45 mm |
| Trace widths | 0.25 mm minimum; power nets request 1 mm with narrower pad escapes |
| Clearance rules | Trace/pad 0.15 mm; via/pad 0.20 mm; board edge 0.50 mm |
| Ground pour | 0.20 mm clearance, 0.60 mm trace margin; solid connections |

Ground stitching is beside both shunts, C3 and the logic supply. U1's four thermal vias remain centered under its exposed ground pad. Ground copper is included in the physical continuity check; negative tests prove that removing the pours creates failures. Solid pour connections may need additional soldering heat, and U1's filled/capped via process still needs assembler confirmation.

## Power copper measurements

These are total planar route lengths, summed across branches; via barrel lengths are excluded. A width range includes narrow fanout sections as well as wider tracks. It does not establish a continuous-current or transient rating.

| Net | Total routed length (mm) | Width range (mm) |
|---|---:|---:|
| VIN | 10.638 | 1.000 |
| VIN_FUSED | 11.329 | 0.405–1.000 |
| VM | 77.280 | 0.325–1.000 |
| AOUT1 | 22.472 | 0.400–1.000 |
| AOUT2 | 21.943 | 0.250–1.000 |
| BOUT1 | 24.059 | 0.250–1.000 |
| BOUT2 | 26.557 | 0.325–1.000 |
| ISEN_A | 21.298 | 0.400–1.000 |
| ISEN_B | 18.679 | 0.300–1.000 |

[Complete measured geometry](artifacts/routed/routing-metrics.json) is generated by `scripts/record-routing-review.py`. The native trace-length report is also retained, but its net summary includes logical branch/centroid distances; the table above measures actual wire segments. Narrow escape sections, via plating, copper weight and current sharing need thermal/current qualification on a prototype. No 1 A continuous rating is asserted.

## Layer previews

- [Top](artifacts/routed/pcb-top.png)
- [Inner1](artifacts/routed/pcb-inner1.png)
- [Inner2](artifacts/routed/pcb-inner2.png)
- [Bottom](artifacts/routed/pcb-bottom.png)
- [Mounting template](artifacts/routed/mounting-template.svg)

All four layers were visually inspected, including the four hardware keepouts. Native build/schema/routing checks and independent Gerber-mode shorts checks pass. See VALIDATION.md for exact evidence. Physical assembly, temperature, stall behavior, supply transients and chassis fit remain untested.

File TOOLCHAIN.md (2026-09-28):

# Toolchain

Pinned on 2026-09-27. Bun 1.3.9; TypeScript 5.9.3; Biome 2.5.14. `bun.lock` is the dependency lockfile. Registry automatic dependency upgrades are disabled.

| Package | Version |
|---|---|
| tscircuit | 0.0.2646 |
| @tscircuit/cli | 0.1.2167 |
| @tscircuit/core | 0.0.1993-dualtt.6, local archive |
| @tscircuit/circuit-json-util | 0.0.116-dualtt.1, local archive |
| circuit-json | 0.0.506-dualtt.1, local archive |
| @tscircuit/props | 0.0.666 |
| @tscircuit/checks | 0.0.221 |
| @tscircuit/capacity-autorouter | 0.0.938 |

The three active local archives in `vendor/` are unpublished builds from canonical upstream source, not npm releases. Exact base commits, complete patches, tests and logs are in [references/toolchain-fixes](references/toolchain-fixes/README.md). Fixes cover position metadata serialization, real plated-hole IDs, optional board-artwork ownership, physical layer anchors on saved routes at plated connectors, and preservation of local trace widths beside saved vias. Electrical and copper-clearance checks remain unchanged.

The schema suite passed 397 tests / 1,899 assertions. Focused core regression tests, TypeScript and package/declaration builds passed; six saved-route regression cases passed 39 assertions. The complete upstream core suite was not run. `scripts/rebuild-toolchain-fixes.py` documents a clean rebuild from the pinned upstream sources; that complete helper has not been executed from scratch. No installed dependency or generated board JSON is patched at runtime, and the user's separate core checkout was not changed.

`index.circuit.tsx` is the canonical board entrypoint. `lib/saved-routing.ts` holds native-generated route paths consumed through the supported `autoroutingphase` API. All 32 non-GND nets are explicitly assigned to this phase; GND is joined by pours and authored stitching. The default rerender validates route anchors and recreates the copper. `routeRemaining={false}` prevents an extra autorouting pass; it does not disable full physical-connectivity or routing checks.

Commands used for final validation: `tsci check netlist`, `tsci check placement`, `tsci check pin_specification`, `tsci check source`, `tsci check trace-length net.VM`, `tsci build`, native `runAllRoutingChecks`, full schema parsing, project tests, mechanical checks and Gerber-mode shorts. `bun run render` converts unmodified generated Circuit JSON to images.

The earlier partial investigation in `references/core-schema-fix/` is historical. The complete fixes above supersede its unresolved status. No upstream issue, PR or npm publication was made.

The registry runtime preloads dependency symlinks and does not provide Python. The mechanical gate therefore also has a native Bun/TypeScript implementation, equivalent to the original Python check. The cloud build command performs a forced frozen-lockfile install before the complete project build, so preloaded libraries cannot create a mixed dependency graph. No check is omitted.

Alpha.5 additionally removes automatic paste from THT pads, resolves two-terminal orientation with sub-micron imported coordinate rounding, invalidates old unknown-orientation cache entries, and supports outline keepouts in the current schema. No footprint coordinates, polarity or copper are changed by the orientation classifier. Six new/updated assembly regression cases pass; all 25 board tests pass. The utility library’s full run had 137 passes and one unrelated renderer-snapshot mismatch. The core artwork snapshot also differs in one path’s rendering. Both mismatches were reproduced with the prior source and left unchanged; baseline evidence is in references/toolchain-fixes. Type/declaration builds and the changed-function tests pass. The rebuild helper is a source recipe; a complete fresh dependency rebuild has not been rerun.

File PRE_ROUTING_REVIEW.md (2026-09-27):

# Work required before routing

> Historical review from before routing. Current routing and validation status is documented in ROUTING_REVIEW.md and VALIDATION.md. Earlier routing holds/schema failures below describe that historical revision and are superseded.

Review date: 2026-09-27. The user wants a store product for common TT motors; the test bench's regulator does not define its sole power source. Target input remains 3–6 V at the connector including tolerance. Routing is disabled, with no routing approval requested for this incomplete revision.

The user's working RP2040 motor board is now a documented comparison in [REFERENCE_BOARD_REVIEW.md](REFERENCE_BOARD_REVIEW.md). Its delivered and latest designs differ; the comparison adds logical ground-connectivity regression coverage and an outside-pad thermal-via option for review. It does not change our hardware, supply target, or routing state.

## Completed in this revision

- Replaced Q1 with Vishay C222495 and F1 with Littelfuse C178991 to reduce power-path voltage loss. F1 is now a non-resettable fuse. Added actual physical pin-net regression coverage.
- Replaced D1 with documented Littelfuse SMBJ6.0A C83270 and audited the clamp/leakage data.
- Corrected R19 to 56 kΩ to meet the NTC measuring-current limit. Reduced host series resistors to 330 Ω for better high-level margin.
- Derived U1 lead, thermal-copper, mask and paste geometry from TI's drawing. Kept four documented thermal vias and established filled/capped via-in-pad as the proposed process.
- Added proper component wrappers, connector entry directions and pin attributes. Moved motor connectors/test pads and separated the TH1/R19 legends. Native 2D placement is clear.
- Expanded current-limit, thermal, host-first power, FAULT loading and TEMP calculations. No physical ratings are asserted.

## Open before a complete routing-approval package

| Item | Remaining work |
|---|---|
| Regenerative energy and source faults | Bound braking/reversal energy and repetition, hot TVS clamp plus layout overshoot, bulk ripple/ESR and fuse coordination. No universal supply compatibility claim. |
| Component qualification | Finish MLCC DC-bias, shunt TCR/pulse and exact passive/connector footprint review; resolve C25804 supplier stock. |
| Assembly and mechanical | Confirm via fill/cap and stencil process, Q1 paste/mask, connector drill fit, screwdriver/mating space and imported-model alignment. |
| Schematics | Add visible value/part annotations to the custom F1/D1/TH1 symbols and finish the page layout review. Remaining native orientation/padding findings are style suggestions, not electrical errors. |
| Software compatibility | Published core still emits schema-invalid offsets/IDs. Local reproductions and a tested partial generator fix exist; board-level silkscreen ownership additionally needs schema/API agreement. No generated output or validation has been patched. |

## Not a reason to delay independent work

A particular purchased chassis is not required: the accepted generic module is 75 × 60 mm with four 3.2 mm holes on 65 × 50 mm centers. It is not a universal chassis fit. Physical startup, overshoot, thermal, EMI and durability tests follow an approved routed prototype; they remain mandatory before selling a claimed performance rating. GitHub-to-registry automatic synchronization is separate from the PCB design.

The next review must present the updated BOM, all four schematics, assembly plan and placement together. Only explicit approval of that complete revision permits routing. See DESIGN_REVIEW.md, U1_FOOTPRINT.md, VALIDATION.md and ISSUES.md for evidence and limits.

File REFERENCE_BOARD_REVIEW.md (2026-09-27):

# Working reference board comparison

> Historical review from before routing. Current routing and validation status is documented in ROUTING_REVIEW.md and VALIDATION.md. Earlier routing holds/schema failures below describe that historical revision and are superseded.

Reviewed 2026-09-27 from the public tscircuit source, without rebuilding, routing, or modifying the reference board.

The user reports that an ordered board from [imrishabh18/rp2040-motor-controller](https://tscircuit.com/imrishabh18/rp2040-motor-controller) works. The exact ordered revision is uncertain. The latest release is **1.0.28**, dated September 26; its own README identifies **1.0.21** as the previously delivered iteration. That makes 1.0.21 a useful additional comparison, not a confirmed identification of the user's hardware. The user's report is recorded as physical-use evidence for their unit; no new measurements were performed here.

| Item | Delivered-iteration reference, v1.0.21 | Latest reference, v1.0.28 | Dual TT draft |
|---|---|---|---|
| Motor/control architecture | DRV8847, RP2040, NEMA 17 application | DRV8825, RP2040, STEP/DIR | DRV8833; two independent TT motors; external controller |
| Motor supply design | 9 V USB-PD | 20 V USB-PD | 3–6 V at the input terminal |
| Mechanical design | 42.30 × 42.32 mm motor cap; 31 mm mounting square | Same NEMA 17 outline | 75 × 60 mm chassis module; 65 × 50 mm mounting centers |
| Input protection/storage | 2 A PTC, SMBJ11CA, 220 µF bulk | PTC, reverse-current diode, SMBJ22CAQ, 22 µF/50 V bulk | Low-loss MOSFET, 3 A non-resettable fuse, SMBJ6.0A, 2 × 220 µF bulk |
| Temperature interface | TMP102 plus hardware sleep interlock and firmware | Same general interlock architecture | NTC output to host; no automatic cutoff |
| Minimum via sizes | 0.30 mm drill / 0.45 mm pad | 0.30 mm drill / 0.45 mm pad | Same minimums; four declared thermal vias are larger |

Version-specific sources: [v1.0.21](https://tscircuit.com/imrishabh18/rp2040-motor-controller?version=1.0.21), [v1.0.28](https://tscircuit.com/imrishabh18/rp2040-motor-controller?version=1.0.28). Retrieval identifiers and source hashes are in `references/rp2040-reference.json`.

## Changes and decisions from this comparison

- **Check ground by electrical connectivity.** Matching labels can hide separate ground networks across nested circuits. New tests traverse actual source-trace and internal-connection edges, check all 30 required ground returns, and keep power, outputs and sense inputs separate from ground. A deliberate exposed-pad disconnection with another net still named GND must be detected. These are logical checks; physical ground continuity remains a post-routing check.
- **Retain local bypassing and short high-current loops.** The reference uses local capacitors and wider motor/power copper. Apply that placement/routing principle with our driver's pin map and current/thermal calculations; copying its nominal widths would not establish our current rating. No copper was added in this review.
- **Review an outside-pad thermal-via option.** The latest reference places six tented thermal vias beyond its driver pad. This is a useful manufacturing alternative to evaluate for our U1. It does not yet replace our declared four-via, filled/capped option: the packages, heat paths, and paste requirements differ.
- **Keep the TT electrical and mechanical requirements.** The reference's NEMA 17 hole pattern and 9/20 V supply circuits do not establish fit or suitability for 3–6 V TT motors. TI specifies an 8.2 V minimum for DRV8825, so it cannot replace DRV8833 in this input range. See the [DRV8825](https://www.ti.com/lit/ds/symlink/drv8825.pdf) and [DRV8833](https://www.ti.com/lit/ds/symlink/drv8833.pdf) datasheets.
- **Keep temperature claims accurate.** The reference's autonomous temperature interlock is a separate function from our raw NTC output. Our host remains responsible for temperature handling; no interlock or onboard MCU was added.

The reference uses different pinned dependencies and board-specific patches. Its successful hardware use and automated checks are useful evidence, but do not resolve the independently reproduced schema failures in our current pinned toolchain. Power-spike, current, thermal, and assembly limits in PRE_ROUTING_REVIEW.md remain open. Routing remains disabled.

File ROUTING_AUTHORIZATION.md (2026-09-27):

# Routing authorization

On 2026-09-27 the user instructed: “conrue dont stop until we got the boaeed routd”. This explicitly authorizes routing and supersedes the earlier pre-route hold. The earlier review artifacts remain in `artifacts/pre-route` as historical evidence.

The board retains the 75 × 60 mm outline, four M3 holes, four copper layers, and minimum 0.30 mm via drill / 0.45 mm via pad. Schema validation, native electrical/placement/routing checks, thermal-via geometry and minimum-size checks remain mandatory. Completing routing does not qualify the prototype for sale or authorize a manufacturing order.

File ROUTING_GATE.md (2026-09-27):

# Routing status — complete

The user's explicit instruction to continue until routed supersedes the previous pre-route hold. See [ROUTING_AUTHORIZATION.md](ROUTING_AUTHORIZATION.md).

- [x] Native netlist and placement checks pass.
- [x] Full generated Circuit JSON schema validation passes.
- [x] Routing is enabled and all nets are physically connected, including GND through pours and stitching.
- [x] Fresh native routing checks report zero findings; no routing checks are disabled.
- [x] Minimum via drill 0.30 mm / pad 0.45 mm preserved.
- [x] Original four U1 thermal vias preserved and connected to ground.
- [x] Board outline, mounting holes, keepouts and 53 courtyards verified.
- [x] Regression tests protect connections, actual generated geometry and failure cases.
- [x] Four copper-layer previews generated and visually inspected.

This completes routing. Manufacturing and store qualification remain separate: exact assembly process, filled/capped thermal vias, selected chassis fit, temperature/current rating, low-voltage margin and regenerative-spike testing are still pending. No new routing permission is required. Public publication results are recorded in [PUBLICATION.md](PUBLICATION.md).

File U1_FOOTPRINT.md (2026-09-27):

# U1 footprint and thermal assembly review

Source: [TI DRV8833 datasheet](https://www.ti.com/lit/ds/symlink/drv8833.pdf), PWP0016C drawing 4224559/B, January 2019. `lib/driver-footprint.tsx` implements the land-pattern example rotated 90° so pin 1 is at bottom left. The supplier import is retained unchanged for provenance and its model/part identity; its original land pattern is not used.

| Feature | Implemented geometry |
|---|---|
| 16 lead pads | 0.45 × 1.50 mm; 0.65 mm pitch; rows at Y=±2.90 mm |
| Exposed-pad copper | 5.00 × 3.40 mm, covered by solder mask outside the opening |
| Exposed opening and paste | 2.31 × 2.46 mm centered; zero mask/paste expansion |
| Lead mask expansion | 0.05 mm per edge |
| Four thermal vias | 0.3048 mm drills, 0.6096 mm pads; exact positions in references/thermal-structures.json |

The two coincident pin-17 pads describe one electrical copper area and its smaller exposed center. The installed tool lacks per-side mask-margin implementation. This uses supported covered-pad and exposed-pad geometry; emitted copper/mask/paste records are tested. Export union/mask fidelity must be checked after routing approval before fabrication.

The four retained vias meet the requested 0.30 mm drill / 0.45 mm pad minima. They are a documented alternative to TI's illustrative via array; their thermal performance is not established by the drawing. They need **filled and copper-capped via-in-pad processing**, with a flat reflow surface. The TI stencil example is 0.125 mm thick. Confirm the exact process and paste coverage with the fabricator/assembler; no order or process acceptance exists yet.

These four holes are conductive thermal-via barrels, not mounting posts. The routed revision connects them and the exposed pad to GND pours; AISEN/BISEN remain separate until their shunts. Physical-connectivity and native routing checks pass. Mechanical fit of the imported 3D model and prototype thermal behavior remain unverified.

`tests/design-connectivity.test.ts` checks all 17 physical pin nets, lead pitch/position/size, thermal copper/opening and emitted paste. The source routing guard hashes this reviewed footprint and allows only the four listed thermal vias. This document is a geometry review, not assembly approval.

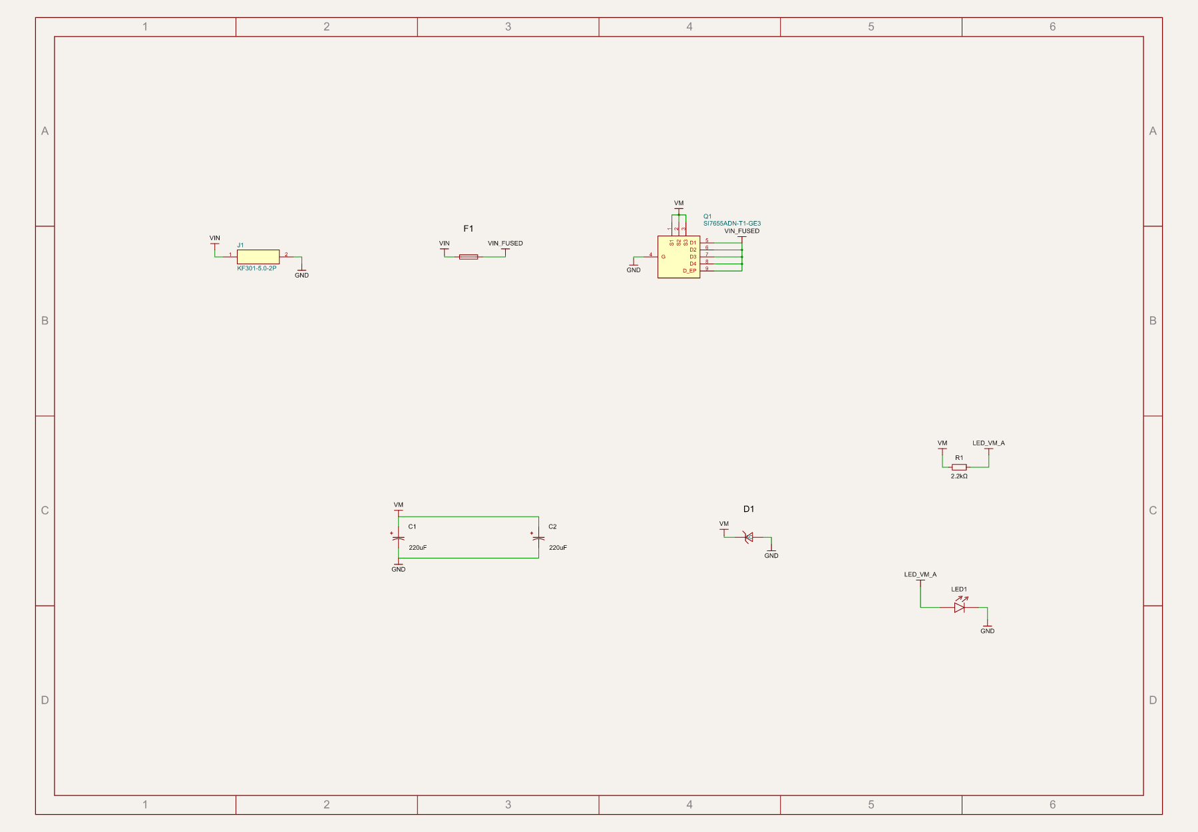
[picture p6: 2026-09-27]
artifacts/pre-route/schematic-Power_Protection.png

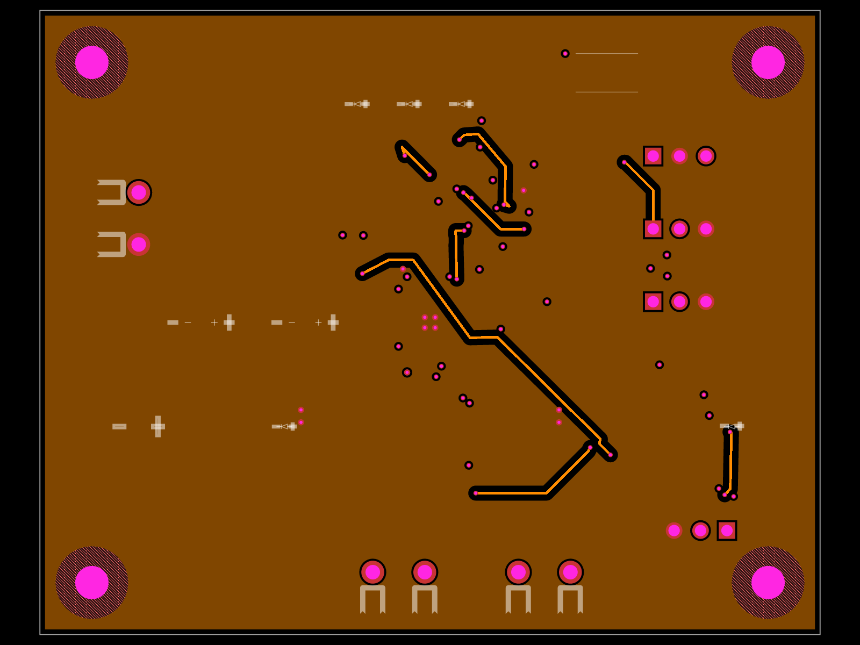
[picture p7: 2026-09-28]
artifacts/routed/pcb-inner1.png

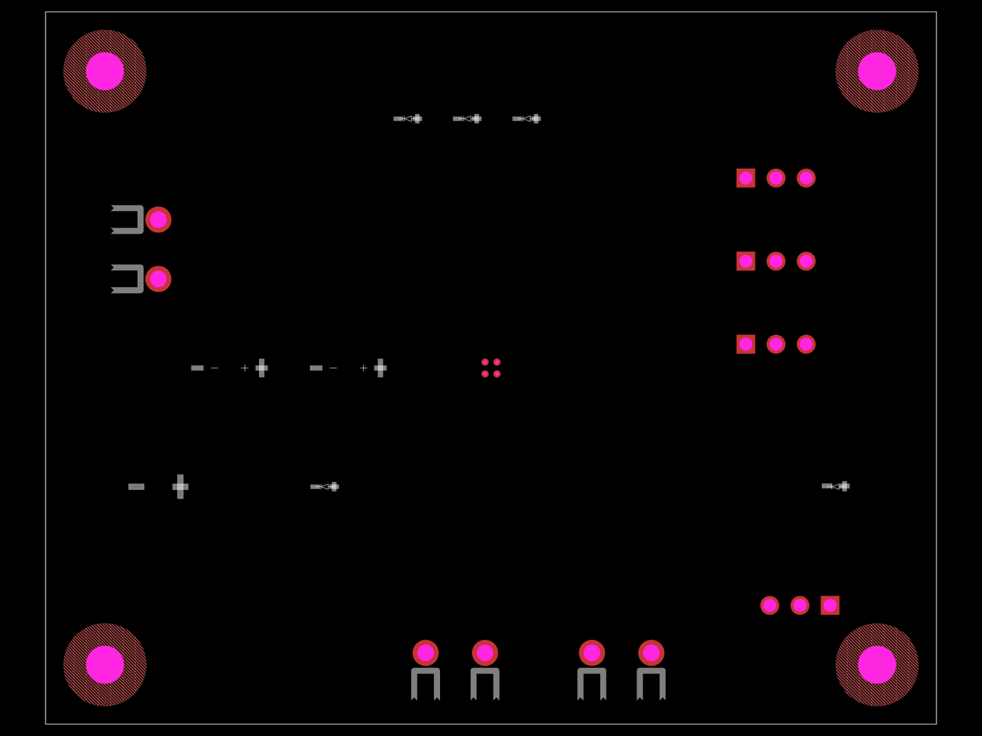
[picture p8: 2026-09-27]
artifacts/pre-route/pcb-bottom-unrouted.png

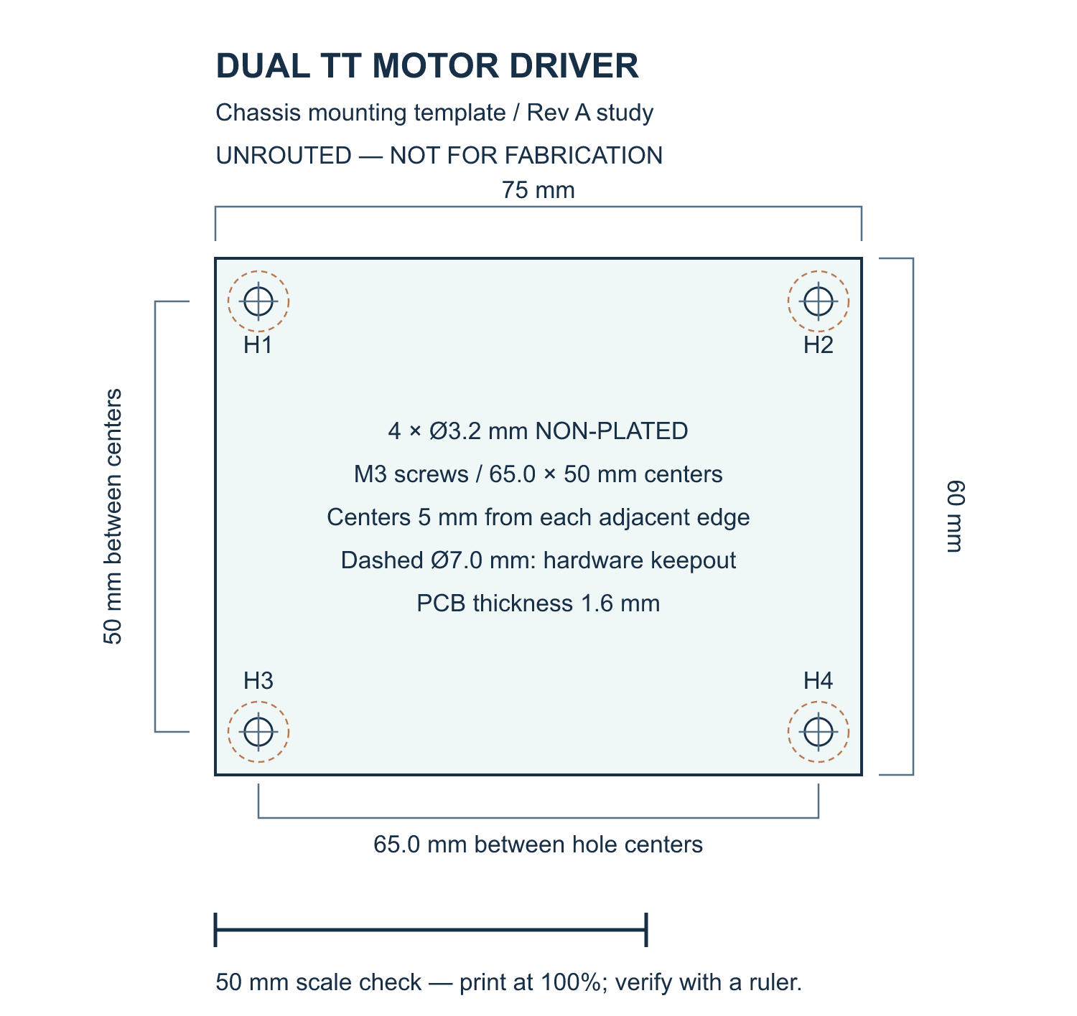
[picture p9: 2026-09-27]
artifacts/routed/mounting-template.png

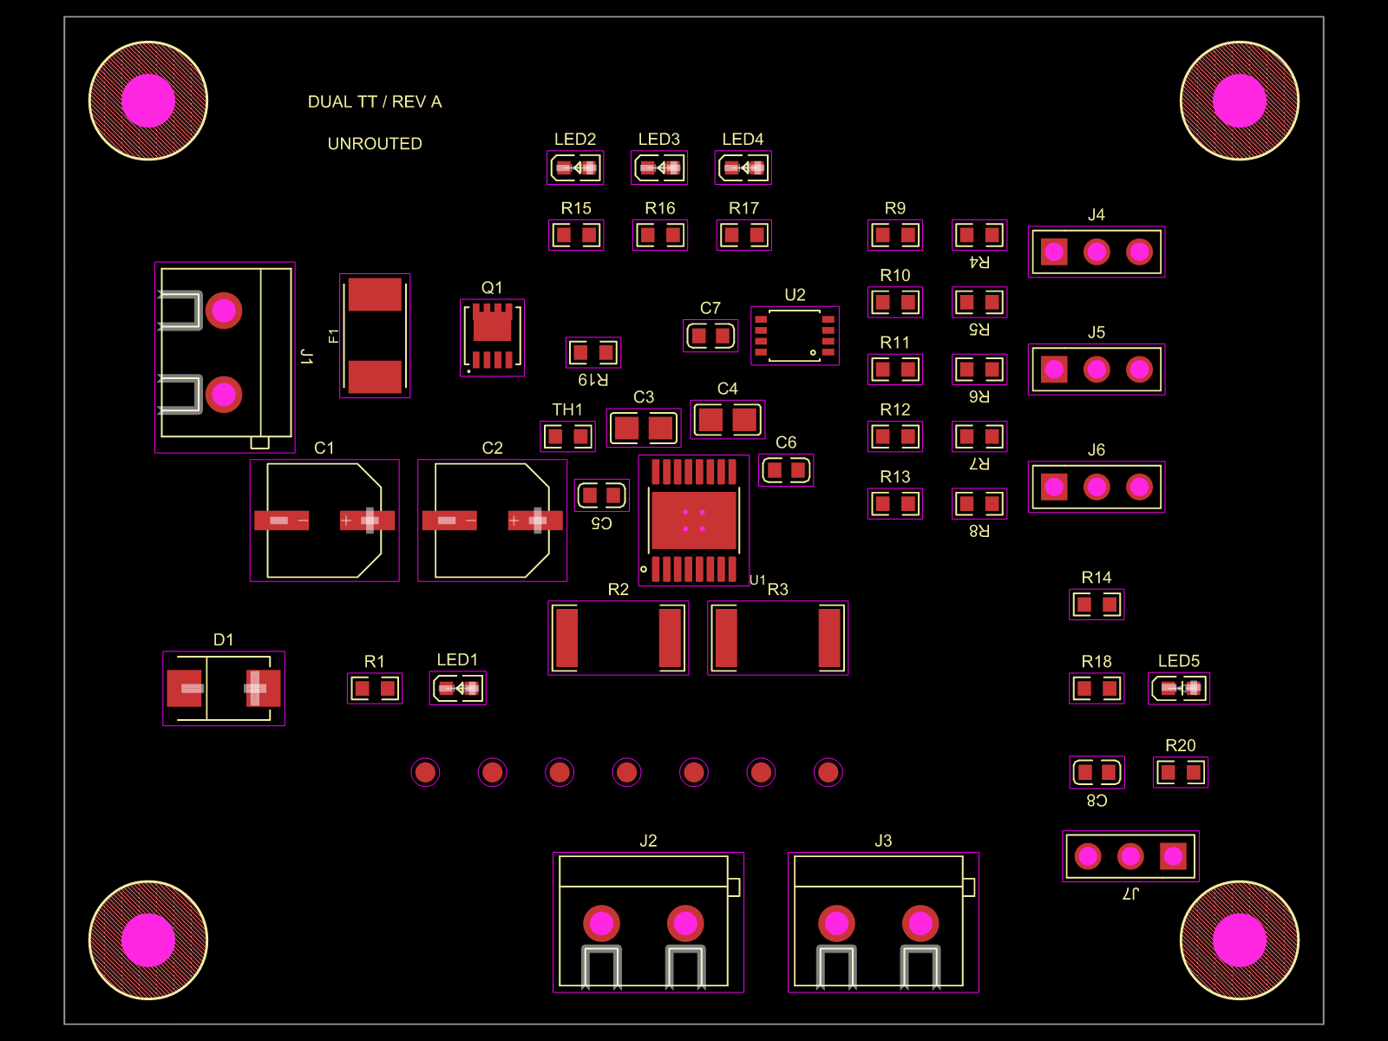
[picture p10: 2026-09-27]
artifacts/pre-route/pcb-top-unrouted.png

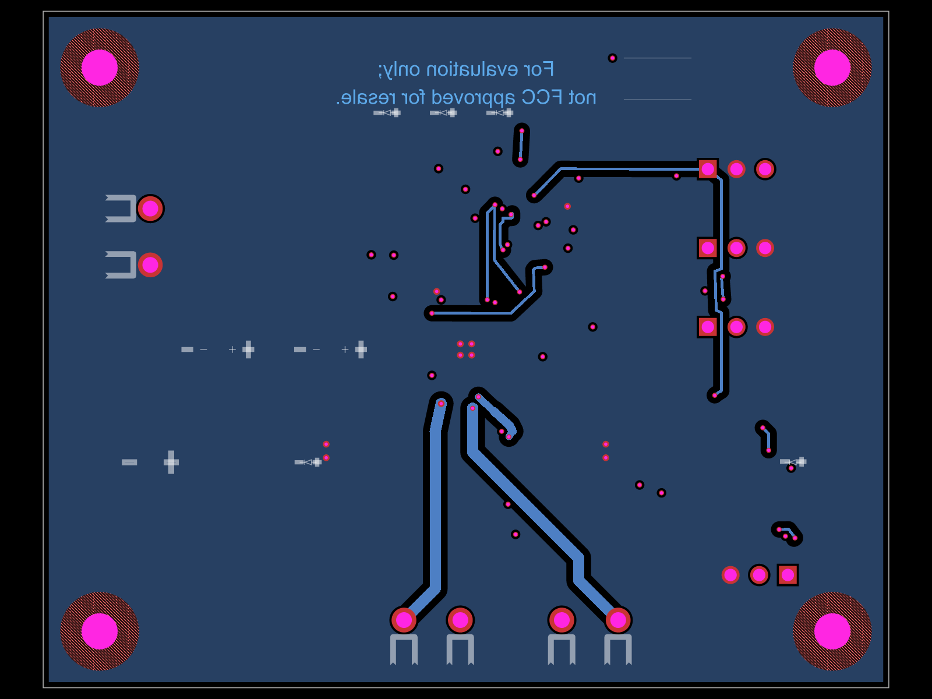
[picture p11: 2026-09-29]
artifacts/routed/pcb-bottom.png

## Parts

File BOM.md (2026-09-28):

# Prototype BOM — alpha.6 with motor-disable button

Generated from actual Circuit JSON: **47 purchased parts, 23 unique C-numbers**, comprising 40 top SMT parts and seven manually fitted connectors per board. Seven bare PCB test pads are not purchased parts. No DNP rows.

Use the [fresh five-board stock audit](artifacts/order-release/STOCK.md) for availability. Final assembly preview, loss allowance and inventory reservation are separate.

| RefDes | Qty | Function | Manufacturer | Exact MPN/value | Package | Ratings/tolerance | C-number | JLC Basic/Extended/other | Assembly service / side | Stock checked + timestamp | Import path | Datasheet/source | Verification status |
| --- | --- | --- | --- | --- | --- | --- | --- | --- | --- | --- | --- | --- | --- |
| J1, J2, J3 | 3 | Power / motor terminals | Cixi Kefa | KF301-5.0-2P | 插件,P=5mm | -30℃~+120℃ 1 1.5 14~22 17A 1x2P 2 250V 2P 5mm Blue Through Hole 插件,P=5mm Screw Terminal Blocks ROHS | C474881 | Extended | TOP inserted; manual THT | 76632 available to order; 2026-09-28T13:56:58.413654+00:00 | imports/KF301_5_0_2P.tsx | https://jlcpcb.com/partdetail/C474881 | Design-file checks pass; manufacturer acceptance and physical qualification pending |
| F1 | 1 | 3 A non-resettable input fuse | Littelfuse | 0453003.MR | 2410 | -55℃~+125℃ 1.65 125V 125V 2.5mm 3A 50A 6.1mm Surface Mount Fuse 2410 Disposable fuses ROHS | C178991 | Extended | TOP SMT; final manufacturer preview required | 1663 available to order; 2026-09-28T13:57:04.305587+00:00 | imports/A_0453003_MR.tsx | https://jlcpcb.com/partdetail/C178991 | Design-file checks pass; manufacturer acceptance and physical qualification pending |
| Q1 | 1 | Low-loss reverse-polarity path | Vishay | SI7655ADN-T1-GE3 | PowerPAK1212-8S | -50℃~+150℃ 1 P-Channel 1.1V 150nC@10V 20V 40A 57W 6.6nF 890pF 930pF 9mΩ@2.5V P-Channel PowerPAK1212-8S MOSFETs ROHS | C222495 | Extended | TOP SMT; final manufacturer preview required | 3495 available to order; 2026-09-28T13:57:10.654403+00:00 | imports/SI7655ADN_T1_GE3.tsx | https://jlcpcb.com/partdetail/C222495 | Design-file checks pass; manufacturer acceptance and physical qualification pending |
| C1, C2 | 2 | Bus bulk storage | Lelon | VZH221M1CTR-0607 | SMD,D6.3xL7.7mm | -45℃~+105℃ 16V 2000hrs@105℃ 220uF 6.3mm 7.7mm ±20% SMD,D6.3xL7.7mm Aluminum Electrolytic Capacitors - SMD ROHS | C285392 | Extended | TOP SMT; final manufacturer preview required | 381 available to order; 2026-09-28T13:57:16.508688+00:00 | imports/VZH221M1CTR_0607.tsx | https://jlcpcb.com/partdetail/C285392 | Design-file checks pass; manufacturer acceptance and physical qualification pending |
| D1 | 1 | Bus transient clamp | Littelfuse | SMBJ6.0A | DO-214AA | Manufacturer: 6 V standoff; 10.3 V clamp at 58.3 A specified pulse; reverse leakage 800 uA max. Catalog 46 nA field is incorrect; see DESIGN_REVIEW.md | C83270 | Extended | TOP SMT; final manufacturer preview required | 4959 available to order; 2026-09-28T13:57:22.608512+00:00 | imports/SMBJ6_0A.tsx | https://jlcpcb.com/partdetail/C83270 | Design-file checks pass; manufacturer acceptance and physical qualification pending |
| R1, R8, R15, R16, R17, R18 | 6 | LED current limiting / host enable series | UNI-ROYAL | 0603WAF2201T5E | 0603 | -55℃~+155℃ 100mW 2.2kΩ 75V Thick Film Resistor ±1% ±100ppm/℃ 0603 Chip Resistor - Surface Mount ROHS | C4190 | Basic | TOP SMT; final manufacturer preview required | 7299835 available to order; 2026-09-28T13:57:28.732950+00:00 | imports/A_0603WAF2201T5E.tsx | https://jlcpcb.com/partdetail/C4190 | Design-file checks pass; manufacturer acceptance and physical qualification pending |
| LED1, LED2, LED3, LED4 | 4 | VM / VIO / A / B LEDs | Hubei KENTO | KT-0603YG | 0603 | -40℃~+85℃ 120° 20mA 2V~2.2V 30mcd~42mcd 40mW 567nm~573nm 576nm Discrete Diode Top-mount Water Clear Yellow Green 0603 LED Indication - Discrete ROHS | C2289 | Extended | TOP SMT; final manufacturer preview required | 34937 available to order; 2026-09-28T13:57:35.150670+00:00 | imports/KT_0603YG.tsx | https://jlcpcb.com/partdetail/C2289 | Design-file checks pass; manufacturer acceptance and physical qualification pending |
| U1 | 1 | Dual H-bridge | Texas Instruments | DRV8833PWPR | TSSOP-16-EP | -40℃~+85℃ 1.5A 2 2.7V~10.8V 360mΩ Bipolar Driver Yes TSSOP-16-EP Stepper Motor Driver ROHS | C50506 | Extended | TOP SMT; final manufacturer preview required | 7526 available to order; 2026-09-28T13:57:41.177992+00:00 | imports/DRV8833PWPR.tsx | https://jlcpcb.com/partdetail/C50506 | Design-file checks pass; manufacturer acceptance and physical qualification pending |
| R2, R3 | 2 | Independent current shunts | Yageo | RL2512FK-070R15L | 2512 | 150mΩ 1W Thick Film Resistor ±1% ±600ppm/℃ 2512 Chip Resistor - Surface Mount ROHS | C876469 | Extended | TOP SMT; final manufacturer preview required | 12 available to order; 2026-09-28T13:57:47.079610+00:00 | imports/RL2512FK_070R15L.tsx | https://jlcpcb.com/partdetail/C876469 | Design-file checks pass; manufacturer acceptance and physical qualification pending |
| C3, C4 | 2 | VM ceramic bypass | Samsung | CL21A106KAYNNNE | 0805 | 10uF 25V X5R ±10% 0805 Multilayer Ceramic Capacitors MLCC - SMD/SMT ROHS | C15850 | Basic | TOP SMT; final manufacturer preview required | 4167679 available to order; 2026-09-28T13:57:53.091530+00:00 | imports/CL21A106KAYNNNE.tsx | https://jlcpcb.com/partdetail/C15850 | Design-file checks pass; manufacturer acceptance and physical qualification pending |
| C5 | 1 | VINT bypass | Samsung | CL10A225KO8NNNC | 0603 | 16V 2.2uF X5R ±10% 0603 Multilayer Ceramic Capacitors MLCC - SMD/SMT ROHS | C23630 | Basic | TOP SMT; final manufacturer preview required | 2265580 available to order; 2026-09-28T13:57:59.142145+00:00 | imports/CL10A225KO8NNNC.tsx | https://jlcpcb.com/partdetail/C23630 | Design-file checks pass; manufacturer acceptance and physical qualification pending |
| C6 | 1 | VCP-to-VM charge pump | Fenghua | 0603B103K500NT | 0603 | 10nF 50V X7R ±10% 0603 Multilayer Ceramic Capacitors MLCC - SMD/SMT ROHS | C57112 | Basic | TOP SMT; final manufacturer preview required | 5150649 available to order; 2026-09-28T13:58:05.080840+00:00 | imports/A_0603B103K500NT.tsx | https://jlcpcb.com/partdetail/C57112 | Design-file checks pass; manufacturer acceptance and physical qualification pending |
| J4, J5, J6, J7 | 4 | Host / diagnostic headers | BOOMELE | 2.54-1*3P针 | 插件,P=2.54mm | -40℃~+105℃ 1 1x3P 2.54mm 2.5mm 3A 3P 3mm 6mm Black Brass Gold Pin Header Through Hole 插件,P=2.54mm Pin Headers ROHS | C49257 | Extended | TOP inserted; manual THT | 208742 available to order; 2026-09-28T13:58:10.918976+00:00 | imports/A_2_54_1_3P_.tsx | https://jlcpcb.com/partdetail/C49257 | Design-file checks pass; manufacturer acceptance and physical qualification pending |
| R4, R5, R6, R7 | 4 | Motor command input series | UNI-ROYAL | 0603WAF3300T5E | 0603 | -55℃~+155℃ 100mW 330Ω 75V Thick Film Resistor ±1% ±100ppm/℃ 0603 Chip Resistor - Surface Mount ROHS | C23138 | Basic | TOP SMT; final manufacturer preview required | 2955508 available to order; 2026-09-28T13:58:16.824950+00:00 | imports/A_0603WAF3300T5E.tsx | https://jlcpcb.com/partdetail/C23138 | Design-file checks pass; manufacturer acceptance and physical qualification pending |
| R9, R10, R11, R12, R14 | 5 | Motor command pulls / FAULT pull-up | UNI-ROYAL | 0603WAF1002T5E | 0603 | 0603 | C25804 | Basic (official JLC catalog) | TOP SMT; final manufacturer preview required | 15231203 available to order; 2026-09-28T13:58:22.732229+00:00 | imports/A_0603WAF1002T5E.tsx | https://jlcpcb.com/partdetail/C25804 | Design-file checks pass; manufacturer acceptance and physical qualification pending |
| R13 | 1 | Enable pull-down | UNI-ROYAL | 0603WAF1003T5E | 0603 | -55℃~+155℃ 100kΩ 100mW 75V Thick Film Resistor ±1% ±100ppm/℃ 0603 Chip Resistor - Surface Mount ROHS | C25803 | Basic | TOP SMT; final manufacturer preview required | 20884103 available to order; 2026-09-28T13:59:04.352604+00:00 | imports/A_0603WAF1003T5E.tsx | https://jlcpcb.com/partdetail/C25803 | Design-file checks pass; manufacturer acceptance and physical qualification pending |
| SW1 | 1 | Momentary motor disable | XKB Connection | TS-1187A-B-A-B | SMD-4P,5.1x5.1mm | -30℃~+85℃ 1.5mm 1.6N 100,000 cycles 12V 5.1mm 5.1mm 50mA Gold No Round Button SPST Surface Mount,Vertical Without Bracket SMD-4P,5.1x5.1mm Tactile Switches ROHS | C318884 | Basic | TOP SMT; final manufacturer preview required | 499801 available to order; 2026-09-28T13:59:10.359661+00:00 | imports/TS_1187A_B_A_B.tsx | https://jlcpcb.com/partdetail/C318884 | Design-file checks pass; manufacturer acceptance and physical qualification pending |
| U2 | 1 | Command XOR indicators | Texas Instruments | SN74LVC2G86DCTR | MSOP-8-2.8mm | -40℃~+125℃ 1.65V~5.5V 1.7V~2V 10uA 2 2 2.3V、2.4V、3.8V 3.6ns@5V,50pF 300mV、400mV、450mV、550mV 32mA 32mA 700mV~800mV 74LVC Series Rear drive protection、Local shutdown mode、Live insertion protection XOR Gate MSOP-8-2.8mm Logic Gates ROHS | C130023 | Extended | TOP SMT; final manufacturer preview required | 3413 available to order; 2026-09-28T13:58:28.680197+00:00 | imports/SN74LVC2G86DCTR.tsx | https://jlcpcb.com/partdetail/C130023 | Design-file checks pass; manufacturer acceptance and physical qualification pending |
| C7, C8 | 2 | Logic bypass / TEMP filter | Yageo | CC0603KRX7R9BB104 | 0603 | 100nF 50V X7R ±10% 0603 Multilayer Ceramic Capacitors MLCC - SMD/SMT ROHS | C14663 | Basic | TOP SMT; final manufacturer preview required | 45106229 available to order; 2026-09-28T13:58:34.900635+00:00 | imports/CC0603KRX7R9BB104.tsx | https://jlcpcb.com/partdetail/C14663 | Design-file checks pass; manufacturer acceptance and physical qualification pending |
| LED5 | 1 | FAULT LED | Hubei KENTO | KT-0603R | 0603 | -40℃~+85℃ 1.8V~2.4V 120° 20mA 300mcd 40mW 615nm~630nm 645nm Discrete Diode Red Water Clear 0603 LED Indication - Discrete ROHS | C2286 | Basic | TOP SMT; final manufacturer preview required | 3378460 available to order; 2026-09-28T13:58:40.807842+00:00 | imports/KT_0603R.tsx | https://jlcpcb.com/partdetail/C2286 | Design-file checks pass; manufacturer acceptance and physical qualification pending |
| R19 | 1 | NTC upper divider resistor | UNI-ROYAL | 0603WAF5602T5E | 0603 | -55℃~+155℃ 100mW 56kΩ 75V Thick Film Resistor ±1% ±100ppm/℃ 0603 Chip Resistor - Surface Mount ROHS | C23206 | Basic | TOP SMT; final manufacturer preview required | 952437 available to order; 2026-09-28T13:58:46.686261+00:00 | imports/A_0603WAF5602T5E.tsx | https://jlcpcb.com/partdetail/C23206 | Design-file checks pass; manufacturer acceptance and physical qualification pending |
| TH1 | 1 | Board temperature | Murata | NCP18XH103F03RB | 0603 | -40℃~+125℃ 0.8mm 1.6mm 100mW 10kΩ 1mW/℃ 310uA 3380K 3434K 3455K ±1% ±1% 0603 NTC Thermistors ROHS | C13564 | Extended | TOP SMT; final manufacturer preview required | 275544 available to order; 2026-09-28T13:58:52.520108+00:00 | imports/NCP18XH103F03RB.tsx | https://jlcpcb.com/partdetail/C13564 | Design-file checks pass; manufacturer acceptance and physical qualification pending |
| R20 | 1 | TEMP series | UNI-ROYAL | 0603WAF1001T5E | 0603 | -55℃~+155℃ 100mW 1kΩ 75V Thick Film Resistor ±1% ±100ppm/℃ 0603 Chip Resistor - Surface Mount ROHS | C21190 | Basic | TOP SMT; final manufacturer preview required | 18140007 available to order; 2026-09-28T13:58:58.394030+00:00 | imports/A_0603WAF1001T5E.tsx | https://jlcpcb.com/partdetail/C21190 | Design-file checks pass; manufacturer acceptance and physical qualification pending |

SW1 is the normally-open XKB TS-1187A-B-A-B tactile button. Hold to disable both motor outputs; release returns control to the host and can restart motion. R8 is now 2.2 kΩ; R13 is 100 kΩ. See [button review](BUTTON_REVIEW.md). Catalog unit prices are historical, exclude assembly/PCB/fees and are not an order quote.

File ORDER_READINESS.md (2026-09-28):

# Order readiness — five-board engineering prototype

The alpha.6 layout and manufacturing exports pass the design checks. The earlier current-path, capacitor-placement, stencil and SMT-orientation findings are resolved. **The files are ready for a five-board prototype quote and final manufacturer preview. No order has been placed or accepted.**

## Button revision

SW1 now provides **HOLD TO DISABLE** control. R8 is 2.2 kΩ and R13 is 100 kΩ to limit pressed GPIO current while preserving enable-high margin. Release may restart motion. Use this alpha.6 packet for the button-equipped board; the previous alpha.5 artwork has no button. [Circuit, contact mapping and validation](BUTTON_REVIEW.md).

## Resolved

- U1 AISEN→R2 is now 7.75 mm long: minimum 0.40 mm, only 1.82 mm below 0.60 mm, and 4.30 mm at 1.00 mm. Previously it included 4.63 mm at 0.25 mm. A simple 35 µm copper estimate falls from about 14 mΩ to about 5.6 mΩ; this is not a calibrated current or thermal rating.
- VINT→C5 and VCP→C6 are each 2.05 mm, on top copper without vias. Previously they were 8.80 mm and 7.02 mm with two layer transitions each. C3/C4 and nearby routes were adjusted to maintain clearance.
- Actual Gerber paste: **110 top apertures, zero bottom apertures**. No paste on any bare test pad or through-hole connector. Through-hole paste was corrected in the canonical generator source.
- All **40 automated SMT placements**, including all five LEDs, pass required supplier-orientation verification. A sub-micron imported LED offset and stale orientation cache were corrected in the generator toolchain. Supplier data confirm the local pin-1 polarity. The unkeyed J1–J7 connectors are deliberately in a separate manual assembly list.
- Via minima remain **0.30 mm drill / 0.45 mm pad**. Four 3.2 mm mounting holes remain non-plated. Filled/capped processing is explicitly specified in the manufacturing notes.

## Evidence

Native netlist: zero errors/warnings. Placement DRC: zero errors/warnings. Build, strict schema, mechanical gates and fresh native routing checks pass. All **26 board tests / 1,139 assertions** pass. The all-layer Gerber shorts check at 40 px/mm reports **no shorts**. Measurement covers all 72 traces, 544 segments and 60 vias, with no measured drill-clearance violations. See [logs](artifacts/order-release/logs), [geometry report](artifacts/order-release/trace-geometry.json), [layer previews](artifacts/routed/pcb-top.svg).

The placement command returns an advisory C7 rotation suggestion even with zero placement DRC errors. Its existing connected route passes copper checks; it was left alone. Harmless same-net bends, seven classified schematic/model warnings and small silkscreen text were also left alone as requested. No DRC or test was disabled.

## Files and order settings

- Upload [fabrication artwork](artifacts/order-release/jlc-fabrication.zip).
- For top-side SMT assembly use [SMT BOM](artifacts/order-release/jlc-smt-bom.csv) and [verified SMT CPL](artifacts/order-release/jlc-smt-cpl.csv): 40 components per board.
- Obtain and fit [J1–J7 separately](artifacts/order-release/manual-tht-bom.csv): seven connectors per board, 35 for the batch.
- Apply [manufacturing notes](artifacts/order-release/MANUFACTURING_NOTES.md): four layers, 1.6 mm, 1 oz outer copper, at least 0.5 oz inner copper, ENIG and **Epoxy-filled & Capped** vias. Confirm production files so the via-in-pad finish and placement preview can be checked before production.

All 23 part types cover five-board placement quantities in the [fresh stock check](artifacts/order-release/STOCK.md). **C876469 is tight: 12 available to order for 10 placements.** The final quote must confirm loss allowance and reserve stock. Do not approve a silent substitute.

The native combined export is retained for provenance. Its full-board CPL warns about unkeyed J4–J7; use the separate SMT BOM/CPL supplied above, not that full-board CPL for automated placement. No assembler preview, paid quote, CAM acceptance or inventory reservation is claimed.

This release is for engineering prototypes. Motor startup/stall, supply spikes, temperature and continuous-current testing remain necessary before selling the board. They are not prerequisites to obtaining the first prototypes.

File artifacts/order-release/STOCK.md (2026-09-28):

# JLCPCB stock — five alpha.6 prototype boards

Public catalog checked 2026-09-28T13:56:58.413654+00:00 through 2026-09-28T13:59:10.359661+00:00. Quantities are not reserved. All 23 exact parts cover placement quantities; the assembler determines extra loss quantities.

| Part | References | Needed | In stock | Available to order |
|---|---|---:|---:|---:|
| [C474881](https://jlcpcb.com/partdetail/C474881) | J1, J2, J3 | 15 | 79187 | 76632 |
| [C178991](https://jlcpcb.com/partdetail/C178991) | F1 | 5 | 1664 | 1663 |
| [C222495](https://jlcpcb.com/partdetail/C222495) | Q1 | 5 | 3495 | 3495 |
| [C285392](https://jlcpcb.com/partdetail/C285392) | C1, C2 | 10 | 571 | 381 |
| [C83270](https://jlcpcb.com/partdetail/C83270) | D1 | 5 | 5036 | 4959 |
| [C4190](https://jlcpcb.com/partdetail/C4190) | R1, R8, R15, R16, R17, R18 | 30 | 7777261 | 7299835 |
| [C2289](https://jlcpcb.com/partdetail/C2289) | LED1, LED2, LED3, LED4 | 20 | 36842 | 34937 |
| [C50506](https://jlcpcb.com/partdetail/C50506) | U1 | 5 | 7599 | 7526 |
| [C876469](https://jlcpcb.com/partdetail/C876469) | R2, R3 | 10 | 37 | 12 |
| [C15850](https://jlcpcb.com/partdetail/C15850) | C3, C4 | 10 | 5354718 | 4167679 |
| [C23630](https://jlcpcb.com/partdetail/C23630) | C5 | 5 | 2679961 | 2265580 |
| [C57112](https://jlcpcb.com/partdetail/C57112) | C6 | 5 | 6996794 | 5150649 |
| [C49257](https://jlcpcb.com/partdetail/C49257) | J4, J5, J6, J7 | 20 | 219103 | 208742 |
| [C23138](https://jlcpcb.com/partdetail/C23138) | R4, R5, R6, R7 | 20 | 3378018 | 2955508 |
| [C25804](https://jlcpcb.com/partdetail/C25804) | R9, R10, R11, R12, R14 | 25 | 22096149 | 15231203 |
| [C130023](https://jlcpcb.com/partdetail/C130023) | U2 | 5 | 3496 | 3413 |
| [C14663](https://jlcpcb.com/partdetail/C14663) | C7, C8 | 10 | 57497999 | 45106229 |
| [C2286](https://jlcpcb.com/partdetail/C2286) | LED5 | 5 | 3868252 | 3378460 |
| [C23206](https://jlcpcb.com/partdetail/C23206) | R19 | 5 | 1023808 | 952437 |
| [C13564](https://jlcpcb.com/partdetail/C13564) | TH1 | 5 | 279667 | 275544 |
| [C21190](https://jlcpcb.com/partdetail/C21190) | R20 | 5 | 22885783 | 18140007 |
| [C25803](https://jlcpcb.com/partdetail/C25803) | R13 | 5 | 22572532 | 20884103 |
| [C318884](https://jlcpcb.com/partdetail/C318884) | SW1 | 5 | 550343 | 499801 |

**R2/R3 C876469: 10 placements, 12 available to order; catalog lossNumber is 2.** Final quote allowance and stock reservation must be confirmed. No replacement has been substituted.

SW1 C318884 and R13 C25803 are Basic parts. R8 reuses C4190; the table includes its increased quantity. J1–J7 are supplied and soldered separately under the manual-THT plan; catalog stock does not imply loose-part shipment.

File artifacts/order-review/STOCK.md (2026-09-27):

# JLCPCB stock for five boards

Checked 2026-09-27T20:55:39.971466+00:00 through 2026-09-27T20:57:40.891855+00:00.

All 21 exact C-numbers had enough available order quantity for the 230 placed components in five boards. This excludes assembler-calculated attrition; stock is unreserved. R2/R3 are the sourcing risk: 10 placements, 37 shown in stock, only 13 available to order. The catalog loss-number field is 2; confirm the actual loss allowance in the PCBA quote. No parts were purchased or reserved.

The official part-page payload fields `overseasStockCount` and `canPresaleNumber` correspond to the visible “In Stock” and “Available Order Qty” labels, checked in the browser for C130023, C876469 and C474881. The available order quantity is the conservative quantity used here. Raw signed media links are not retained.

| References | Part | Need for 5 | In stock | Available to order | Library |
|---|---|---:|---:|---:|---|
| J1, J2, J3 | [C474881](https://jlcpcb.com/partdetail/C474881) · KF301-5.0-2P | 15 | 85,541 | 83,035 | Extended |
| F1 | [C178991](https://jlcpcb.com/partdetail/C178991) · 0453003.MR | 5 | 1,664 | 1,663 | Extended |
| Q1 | [C222495](https://jlcpcb.com/partdetail/C222495) · SI7655ADN-T1-GE3 | 5 | 3,495 | 3,495 | Extended |
| C1, C2 | [C285392](https://jlcpcb.com/partdetail/C285392) · VZH221M1CTR-0607 | 10 | 577 | 391 | Extended |
| D1 | [C83270](https://jlcpcb.com/partdetail/C83270) · SMBJ6.0A | 5 | 5,370 | 5,294 | Extended |
| R1, R15, R16, R17, R18 | [C4190](https://jlcpcb.com/partdetail/C4190) · 0603WAF2201T5E | 25 | 7,860,760 | 7,395,845 | Basic |
| LED1, LED2, LED3, LED4 | [C2289](https://jlcpcb.com/partdetail/C2289) · KT-0603YG | 20 | 36,952 | 35,220 | Extended |
| U1 | [C50506](https://jlcpcb.com/partdetail/C50506) · DRV8833PWPR | 5 | 8,203 | 8,042 | Extended |
| R2, R3 | [C876469](https://jlcpcb.com/partdetail/C876469) · RL2512FK-070R15L | 10 | 37 | 13 | Extended |
| C3, C4 | [C15850](https://jlcpcb.com/partdetail/C15850) · CL21A106KAYNNNE | 10 | 5,520,528 | 4,356,229 | Basic |
| C5 | [C23630](https://jlcpcb.com/partdetail/C23630) · CL10A225KO8NNNC | 5 | 2,746,974 | 2,345,434 | Basic |
| C6 | [C57112](https://jlcpcb.com/partdetail/C57112) · 0603B103K500NT | 5 | 7,096,854 | 5,250,849 | Basic |
| J4, J5, J6, J7 | [C49257](https://jlcpcb.com/partdetail/C49257) · 2.54-1*3PPin | 20 | 220,468 | 210,430 | Extended |
| R4, R5, R6, R7, R8 | [C23138](https://jlcpcb.com/partdetail/C23138) · 0603WAF3300T5E | 25 | 3,462,489 | 3,047,816 | Basic |
| R9, R10, R11, R12, R13, R14 | [C25804](https://jlcpcb.com/partdetail/C25804) · 0603WAF1002T5E | 30 | 22,819,933 | 16,104,762 | Basic |
| U2 | [C130023](https://jlcpcb.com/partdetail/C130023) · SN74LVC2G86DCTR | 5 | 3,496 | 3,415 | Extended |
| C7, C8 | [C14663](https://jlcpcb.com/partdetail/C14663) · CC0603KRX7R9BB104 | 10 | 51,313,336 | 39,226,968 | Basic |
| LED5 | [C2286](https://jlcpcb.com/partdetail/C2286) · KT-0603R | 5 | 3,997,054 | 3,525,466 | Basic |
| R19 | [C23206](https://jlcpcb.com/partdetail/C23206) · 0603WAF5602T5E | 5 | 1,037,232 | 972,182 | Basic |
| TH1 | [C13564](https://jlcpcb.com/partdetail/C13564) · NCP18XH103F03RB | 5 | 284,309 | 280,261 | Extended |
| R20 | [C21190](https://jlcpcb.com/partdetail/C21190) · 0603WAF1001T5E | 5 | 23,613,042 | 19,016,118 | Basic |

The terminal C474881 page explicitly lists Wave Soldering and Economic and Standard PCBA. Eligibility of a complete assembly job still requires the final BOM/CPL match and quote; the existing manual-THT assembly plan has not been changed. JLCPCB library parts are for its PCBA jobs and cannot be shipped separately.

Machine-readable evidence: [jlc-stock.json](jlc-stock.json), with individual response hashes and timestamps.

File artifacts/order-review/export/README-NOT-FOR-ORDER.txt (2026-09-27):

REVIEW ONLY — NOT APPROVED FOR ORDER
See ../../../ORDER_READINESS.md and ../STOCK.md.
Generated without post-processing from the reviewed board. Paste and CPL issues remain.

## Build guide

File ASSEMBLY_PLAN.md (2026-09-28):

# Assembly plan — prototype SMT packet

40 purchased SMD parts on TOP; 7 through-hole connectors inserted from TOP (3 terminals and 4 headers). Seven test pads, four footprint thermal vias and the routing/stitching vias are PCB features. No bottom purchased components. No DNP parts. No approved substitutions. The board is now routed; assembly process qualification and a fabrication order remain pending.

TOP SMT reflow precedes manual/selective through-hole soldering. JLC catalog stock does not establish turnkey THT assembly. Service eligibility, sourcing fees, panelization, minimum board constraints and final quote remain unverified.

Inspect U1 pin 1 and soldered exposed pad; confirm Q1 G/S/D orientation, TVS cathode, both bulk capacitor positive pads and every LED polarity. Red and green imported LEDs have different numeric anode/cathode mappings; connections use semantic labels. Verify connector drills against actual pin diagonal and tolerances before release.

U1 now uses the TI-derived footprint in `lib/driver-footprint.tsx`, with 0.45 × 1.50 mm lead pads, corrected thermal opening and explicit paste. See [U1_FOOTPRINT.md](U1_FOOTPRINT.md). Its four retained thermal vias require filled and copper-capped processing and assembler review of the 0.125 mm stencil example. No completed process approval is claimed.

Q1 is now Vishay C222495 in PowerPAK1212-8S. Imported lead pads are 0.405 × 0.990 mm with 3.860 mm overall row span; drain copper is 2.235 × 1.725 mm. These match [Vishay AN826 land dimensions](https://www.vishay.com/docs/72597/72597.pdf); lead pitch is 0.650 mm per the [current case outline](https://www.vishay.com/docs/63919/ppak1212-8s.pdf). Original pad 9 is exposed DRAIN, not ground. It must join pins 5–8 on VIN_FUSED. Reflow and under-package inspection are needed; hand-iron rework is not the recommended process. The generated stencil has been inspected; imported 3D model alignment is not dimensionally qualified.

F1 is now non-resettable Littelfuse C178991. Its raw import's oversized pads were replaced by `lib/fuse-footprint.tsx`: two 1.96 × 3.15 mm pads, 2.95 mm inner gap, from the [manufacturer recommended layout](https://www.littelfuse.com/assetdocs/fuse-451-and-453-datasheet?assetguid=533cd5cc-956c-4243-867f-6ab5a62f6ba1). Rounded printed dimensions give 6.87 mm outer span versus 6.86 mm annotated. The original imported model and part identity are retained. The fuse is unpolarized and now rotated 90° on the PCB for clearance.

Thermal-pad paste, reflow profile, moisture handling, tall capacitor clearances, screw/tool access, header mating access and motor-side solder-tail clearance remain blocked pending final geometry and exact process. CAD models exist as import URLs but have not been dimensionally verified. No 3D-fit PASS is claimed.

Mounting proposal: four M3 insulating standoffs, nominally 10 mm tall, with screws/washers contained within each 7 mm hardware zone. Hole positions and 2D courtyard clearances pass the mechanical check; standoff height, actual screw lengths, mating access and chassis fit are not physically verified. See MECHANICAL.md.

Alpha.6 manufacturing files are in [artifacts/order-release](artifacts/order-release/MANUFACTURING_NOTES.md). The actual Gerbers have 110 TOP paste flashes and no BOTTOM paste. Through-hole connectors and bare test pads have no paste. All 40 automatic SMT placements pass required JLCPCB supplier-orientation verification, including LEDs. The seven manual connectors are in their own BOM. These files resolve the prior export findings; final quote, CAM and assembly preview remain manufacturer steps.

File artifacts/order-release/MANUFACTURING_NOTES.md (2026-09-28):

# Dual TT motor driver — alpha.6 prototype fabrication and assembly

Quantity: 5 PCBs. Board: 75 × 60 mm, 1.6 mm thick, FR-4, four layers. Stack: F_Cu / In1_Cu / In2_Cu / B_Cu. Outer copper 1 oz; inner copper at least 0.5 oz. No controlled-impedance requirement. Green solder mask, white silkscreen, ENIG finish.

**Via covering: Epoxy-filled & Capped (resin filled, copper plated over, flat).** Apply to all 0.3000 mm and 0.3048 mm via drills, including the four thermal vias under U1. Do not substitute tenting or ink plugging. Do not fill connector plated holes or the four 3.2 mm non-plated mounting holes. Follow the supplied mask openings. Keep mounting holes non-plated.

U1 via centers, in Gerber/board coordinates (mm): (+0.500126,+0.499872), (-0.499872,+0.499872), (+0.500126,-0.500126), (-0.499872,-0.500126). Verify the exact drill positions against the supplied drill file and thermal-structure reference before CAM approval. U1 has 0.3048 mm via drills and 0.6096 mm pads; other vias have ≥0.30 mm drill / ≥0.45 mm pad.

TOP SMT assembly only: 40 components per PCB, 200 placements in this batch. Use jlc-smt-bom.csv and jlc-smt-cpl.csv together. CPL units are mm; origin is the board center, X right/Y up. Do not add an origin offset to only one file. All SMT rotations were matched to supplier footprints. Confirm pin 1 and polarity in the assembler’s preview: U1, U2, Q1, D1, C1/C2 and LED1–LED5. Confirm SW1 contact-row orientation against the supplied placement file; 90° rotation is not interchangeable.

J1–J7 are fitted and soldered manually after reflow, all inserted from TOP; not included in the automated SMT BOM/CPL. Supply 15 KF301-5.0-2P terminals and 20 straight 1×3 2.54 mm headers for five boards. Square header pads identify pin 1. Match J1/J2/J3 wire-entry direction to the outline drawing. Bare TP1–TP7 need no components or paste.

Stencil: TOP only, 110 apertures; B_Paste is empty. Start assembler review with 0.125 mm thickness, matching the TI U1 stencil example. U1 exposed-pad aperture is 2.31 × 2.46 mm; solderable exposed opening is the same. Confirm paste/reflow suitability and inspect U1/Q1 hidden joints. Use manufacturer lead-free reflow limits and moisture handling.

Select confirmation of production files. Confirm filled/capped via-in-pad processing, SMT placement preview, finished mask/paste and component availability before releasing production. C876469 has only 12 available-to-order units for 10 placements at the recorded stock check; quote loss allowance and reserve stock. No substitutions without electrical/footprint review.

Source: https://jlcpcb.com/help/article/pcb-via-covering and the checked-in U1_FOOTPRINT.md. This packet is an engineering prototype, without an established continuous-current or thermal rating.

SW1 is a momentary HOLD TO DISABLE control: motors coast while held; releasing can restart them. It does not disconnect supply power. After assembly, verify released/pressed contact mapping with no motors attached before the first powered test.

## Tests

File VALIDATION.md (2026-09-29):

# Validation — routed prototype

## Alpha.7 schematic review — 29 September 2026

Native schematic-placement checks report no collisions or overlaps; all four rendered sheets were visually reviewed. Function/rating notes appear beside U1, U2 and Q1. Full build, schema, netlist, mechanical and routing checks pass; 27 board tests retain all 1,139 assertions. Existing non-blocking placement/symbol advisories remain documented. All PCB, CAD and electrical connectivity records match alpha.6, and its manufacturing packet is unchanged. [Schematic review](SCHEMATIC_REVIEW.md), [comparison evidence](artifacts/schematic-review/unchanged-hardware.json) and [logs](artifacts/schematic-review/logs/).

## Alpha.6 manufacturing evidence

Run 28 September 2026. Current evidence: `artifacts/order-release/logs/`; prior reports are historical. These checks validate design files, not physical boards.

| Check | Result |
|---|---|
| Format and TypeScript | PASS |
| Native netlist | 0 errors / 0 warnings |
| Placement DRC | 0 errors / 0 warnings; CLI also reports one advisory C7 orientation suggestion |
| Full build, strict Circuit JSON schema and routing contract | PASS; 7 classified schematic/model warnings |
| Fresh native routing / physical connectivity | 0 findings |
| Board regression tests | 26 pass / 1,139 assertions, including negative connectivity cases |
| Gerber shorts, four layers, 40 px/mm | No shorts detected |
| Mechanical checks | PASS; 75×60×1.6 mm, four 3.2 mm NPTH holes, 65×50 mm centers |
| Trace/drill measurement | 72 traces / 544 segments / 60 vias; 0 measured drill-clearance violations |
| Actual exported stencil | 110 TOP / 0 BOTTOM flashes; no THT/test-pad paste |
| SMT BOM/CPL | 40 matching designators; all supplier rotations required and verified |
| Live JLC stock | 23 exact types cover five-board placements; C876469 loss allowance/stock reservation still needs final quote |
| Physical motor/current/thermal tests | Not yet run; prototype test plan applies |

Vias: 49 at 0.30/0.45 mm, seven at 0.30/0.60 mm, four U1 thermal vias at 0.3048/0.6096 mm. All span four copper layers. Ground pours cover top, inner1 and bottom; inner1 also carries signals.

Retained warnings: Q1/TH1 reference-prefix conventions; Q1 IC-style power/ground attributes; F1/D1/TH1 schematic-reference association. Visible reference text and electrical connections remain checked. No warnings or DRC were suppressed. The C7 orientation heuristic is advisory and its existing connected copper passes routing checks.

The separate PCB-bitmap shorts mode is not claimed as passing; the completed shorts check uses exported Gerber artwork. Manufacturer CAM, component reservation and assembly preview have not been accepted. [Order readiness and settings](ORDER_READINESS.md).

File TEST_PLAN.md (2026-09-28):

# Prototype test plan — ALL PHYSICAL TESTS NOT RUN

No board has been manufactured. No simulation or laboratory result is claimed. Final numerical supply/current/thermal limits must be settled before executing hazardous tests.

1. Record motor part/lot, board revision, supply limits, host/firmware, ambient and calibrated instruments. Confirm motor/shaft/gearbox/fastener fit and component clearance against a sample.
2. Inspect polarity, lead soldering and exposed pad; measure unpowered rail resistance and shorts.
3. Power from a low-current limited source with ENABLE low. Stop on unexpected current, heating, odor or a wrong rail. Check VIO and TEMP ranges before attaching a host.
4. Exercise VM-first, VIO-first, power removal, reset and disconnected host. Require no unintended motor drive; confirm FAULT/TEMP do not backfeed an unpowered host beyond its specified limit.
5. Verify both channels' coast/forward/reverse/brake commands and all five LEDs. Confirm command LEDs may remain lit during sleep. Check wake delay before enabling PWM.
6. Run low-duty no-load starts, then controlled load and simultaneous starts. Sweep the intended PWM range only after host timing and motor-current assumptions are approved.
7. Measure per-channel chopping and shunt temperature with brief controlled blocked-rotor pulses. Use a host timeout, conservative current limit and immediate stop. No unlimited stall test. Define current min/max from reviewed comparator/shunt tolerances first.
8. Capture reversal, braking, both-channel stop, hot plug and source disconnect bus waveforms using an energy-limited setup. Require VM to remain within the reviewed operating envelope, with absolute maximum as a hard abort threshold; final margin must be defined before testing.
9. Test actual lowest input under full specified load, wiring and both-channel starts. Require VM at U1 ≥2.7 V with margin. The present 3 V input target is not approved.
10. Perform both-channel thermal soak at the specified ambient/load/duty only after the copper and thermal design are validated. Establish component-temperature limits with derating, below relevant ratings; derive continuous board rating from measurements.
11. Compare TEMP to an independent board-temperature probe across the intended range; validate source impedance, filter settling and ADC acquisition. Force NTC open/short and require host disable plus explicit sensor-fault handling.
12. Verify fault reporting and recovery. Store raw waveforms and results, including failed runs.

Use differential or isolated methods on H-bridge outputs. Never attach an earth-referenced scope ground clip to a switching motor terminal. Final test acceptance tables, temperature limits, supply margin and PWM endpoints remain blocked by the design review; this is a plan, not release evidence.

## Alpha.6 motor-disable button

First measure ENABLE with no motors attached. Released with host enable high: verify a valid high at 3.3 V and 5 V host supplies. Pressed: verify low and less than 2.5 mA host output current at VIO≤5.25 V. Released with host enable low/disconnected: verify the driver stays asleep. With wheels lifted, verify both channels coast while held and can resume on release. Check contact bounce, wake delay and motor-supply transients. SW1 is not a maintained stop, brake or power disconnect.

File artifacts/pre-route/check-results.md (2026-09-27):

# Native tscircuit checks — alpha.2 unrouted revision

Run 2026-09-27 with tscircuit 0.0.2646 / CLI 0.1.2167. Source and artifact hashes accompany this revision. Routing remains disabled.

| Command / scope | Result | Evidence |
|---|---|---|
| `tsci check netlist index.circuit.tsx` | 0 errors / warnings | [log](logs/netlist.log) |
| `tsci check source index.circuit.tsx` | See diagnostic-category output | [log](logs/source-diagnostics.log) |
| `tsci check placement index.circuit.tsx` | 0 errors / warnings | [log](logs/placement.log) |
| `tsci check pin_specification index.circuit.tsx` | 0 errors; 2 discrete-Q1 category warnings | [log](logs/pin-specification.log) |
| `tsci check shorts dist/index/circuit.json --mode pcb --layer all` | No shorts in existing copper | [log](logs/shorts.log) |
| `tsci check schematic-placement index.circuit.tsx` | Remaining style/readability suggestions retained | [log](logs/schematic-placement.log) |
| `bun run build` | FAIL at strict generated-schema guard | [log](logs/project-build.log) |
| `bun test` | 15 pass / 1 schema integration failure | [log](logs/tests.log) |

Shorts received prebuilt JSON; no routing solver or Gerber export ran. Native commands can return zero despite warnings, so results come from diagnostics, not exit status alone. Circuit output has no traces/pours and only the four allowlisted U1 thermal vias. Old placement-u1/u2 logs are historical evidence from the earlier study, not the current geometry. Current full-board placement supersedes them. Full schema failure is not hidden by clean native checks.

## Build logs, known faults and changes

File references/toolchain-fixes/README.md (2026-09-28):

# Reproducible local generator fixes

These are **unpublished local builds**, not upstream releases. The board's package manifest and lockfile use the checked-in archives in `vendor/` explicitly. No installed dependency or generated board JSON is edited at runtime.

Canonical upstream commits are in `core-base.txt` and `circuit-json-base.txt`. The patches contain source changes, regression tests and visual snapshots. `scripts/rebuild-toolchain-fixes.py` fetches those exact sources into a new temporary directory, applies the patches, validates and packages them. It does not modify an existing tscircuit checkout.

The fixes make generated position metadata match its string schema, give rectangular-pad plated holes real generated IDs, omit absent component ownership on board mounting holes/artwork, and model board/group artwork ownership as optional in Circuit JSON. Invalid owner values still fail validation. Copper geometry and electrical checks are not weakened.

Validation: the schema suite passed 397 tests / 1,899 assertions. Core's focused regression tests, TypeScript and package/declaration build passed; the complete upstream core suite was not run. Logs are alongside the patches. All real board elements are still parsed against the complete schema.

No upstream issue, PR or npm publication has been made. These archives travel with this board for reproducibility while the canonical fixes await separate upstream review.

Saved-route fixes accept the actual copper layers of plated connector pads and preserve existing via contacts with their local trace widths. The six saved-route regression tests pass (39 assertions), including invalid anchors/layers/coverage and existing fanout cases. The generated board is still checked by the complete native routing checks. No electrical check is bypassed.

Alpha.5 uses core dualtt.6 plus circuit-json-util dualtt.1. These add THT stencil correction, LED axis-rounding classification, orientation cache v4 and outline-keepout transform support. `core-assembly-regressions.log` records six passing assembly cases. Two unrelated visual snapshot mismatches reproduce on baseline source (`core-baseline-artwork.log`, `utility-baseline-snapshot.log`); their snapshots were not rewritten. All board checks pass independently.

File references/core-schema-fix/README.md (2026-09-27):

# Local core serialization investigation

> Historical review from before routing. Current routing and validation status is documented in ../../ROUTING_REVIEW.md and ../../VALIDATION.md. Earlier routing holds/schema failures below describe that historical revision and are superseded.

Base: tscircuit/core commit `521de2c447926e29a0334fd0bf08874536abd205`, package 0.0.1993, cloned separately at `/private/tmp/dual-tt-core-schema-fix`. The user's existing core checkout was not edited.

`core.patch` fixes numeric display offsets on components/groups and null IDs on pill holes with rectangular pads. Regression tests fail before the fix; the five focused tests pass afterward (59 assertions), TypeScript passes and the package/declarations build succeeds. Two visual snapshots change only the displayed numeric offset formatting, not placement. The full upstream suite has not run; this is a prepared partial fix, not an accepted release.

The separate silkscreen reproduction still fails: board/group-level artwork has no component owner, while the published schema requires one. Changing null to undefined does not solve that contract. It needs a coordinated core/schema change. No generated board JSON was edited, no checks were relaxed and no local dependency link was added to this PCB project.

No upstream issue or PR has been submitted. Publishing this PCB's source was authorized; publishing upstream reports or patches was not. A reviewed, published compatible dependency is still needed before the real board gate can pass.

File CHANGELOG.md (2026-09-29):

# Changelog

## 0.1.0-alpha.8 — bottom evaluation label, 2026-09-29

Added “For evaluation only; not FCC approved for resale.” as two lines of 1.8 mm bottom silkscreen text. Copper, drills, solder mask, paste, placement and electrical connections are unchanged. Updated previews and generated a separate fabrication ZIP in `artifacts/silkscreen-review/`; the previous alpha.7 release and alpha.6 order packet do not contain this label.

## 0.1.0-alpha.7 — schematic design review, 2026-09-29

Added native schematic notes beside U1, U2 and Q1 with their functions and voltage/current limits. Labeled all connectors, the disable button and temperature measurement. Separated host-input schematic sections and diagnostic test access to remove obstructing wires, and kept notes inside the page boundaries. Electrical connectivity, all PCB/CAD records and the alpha.6 manufacturing packet are unchanged.

## 0.1.0-alpha.4 — portable cloud build

Unchanged routed copper. Ported the mechanical geometry gate to Bun/TypeScript, preserving all checks, because the registry has no Python runtime. The cloud build reinstalls the frozen dependency graph to replace preloaded package symlinks.

## 0.1.0-alpha.3 — routed prototype, 2026-09-27

Completed all signal/power routes and ground copper with six additional ground stitches. Preserved the 75 × 60 mm chassis outline, M3 mounting pattern and 0.30/0.45 mm via minima. Added validated native saved routes, strict physical-connectivity regression cases, all-layer previews and passing routing evidence. Canonical generator/schema fixes are included as explicit, reproducible local packages with source patches. Physical assembly/current/thermal qualification remains pending.

## 0.1.0-alpha.1 — electrical study, 2026-09-27

- Initialized isolated tscircuit workspace and pinned the stable tscircuit release.
- Imported 19 real supplier component types and drafted four electrical sheets.
- Added 0.30 mm via-hole / 0.45 mm via-pad minimums and source/build routing lock.
- Added negative guard tests and preserved the generated-schema failure.
- Recorded candidate BOM, sourcing results, preliminary calculations and open review gates.
- Added a 75 × 60 × 1.6 mm chassis-module outline, four 3.2 mm M3 mounting holes on 65 × 50 mm centers, four-layer hardware keepouts, measured courtyard checks and a printable template.
- Reoriented passive parts and moved the diagnostic header to clear the mounting hardware; placement orientation analysis is clean.
- User authorized public GitHub and tscircuit publication; actual results are in PUBLICATION.md. No routing or fabrication release.

## 0.1.0-alpha.2 — unrouted electrical and placement revision

Lower-loss Q1 and non-resettable F1; documented Littelfuse TVS; corrected NTC excitation and host input resistors; TI-derived U1 footprint/paste; manufacturer F1 footprint; native connector directions and electrical wrappers; pin/geometry/current-margin regression checks. Mounting remains 75 × 60 mm with four M3-clearance holes. Strict schema gate remains failing on documented upstream defects. Not approved for routing, fabrication or sale.

## Working-reference review — 2026-09-27

Compared the user's working RP2040 board's delivered-iteration and latest sources. Added logical ground-network and deliberately disconnected-ground regressions. Hardware, parts, dimensions and routing lock are unchanged; full schema validation still fails.

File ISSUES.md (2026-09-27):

# Toolchain issues and remaining limitations

Current board build, schema and native routing checks pass. Historical failing output remains in `artifacts/pre-route/`; it is superseded by `artifacts/routed/`.

## Resolved in explicit local toolchain builds

- **TOOL-001 — numeric position metadata:** canonical core now serializes display offsets as the schema's strings.
- **TOOL-004 — generated IDs/ownership:** rectangular plated pads receive real IDs; mounting holes and board/group silkscreen omit nonexistent component owners. The coordinated schema permits absent artwork ownership while still rejecting invalid values.
- **Saved connector route layers:** route endpoints now use the physical conductive layers of through-hole pads, not only the one layer chosen for autorouting input.
- **Saved via contact widths:** existing route contacts and their local widths are preserved; missing contacts use adjacent widths instead of widening narrow escape sections.

These fixes have focused regression tests, including invalid-anchor/layer/coverage cases. They are unpublished builds included in `vendor/`; see TOOLCHAIN.md and `references/toolchain-fixes/`. No generated Circuit JSON, native DRC or installed dependency was patched to hide a finding. No upstream publication is claimed.

## Classified visible warnings

- **TOOL-002 — discrete component modeling:** Q1 has nine physical pads and uses a generic chip with explicit, tested source/gate/drain mapping. The native three-terminal MOSFET API cannot express this footprint directly. IC-style checks therefore report no requires_power/requires_ground pins, and the Q prefix is flagged. Adding fake IC supply pins would be incorrect.
- TH1 is an NTC modeled with a resistor primitive and intentionally uses the TH reference prefix.
- F1, D1 and TH1 have visible reference labels supplied by wrappers, but the schematic styling checker does not associate them with their custom symbols. Three warnings remain; these are not physical routing errors.
- **TOOL-005 — schematic pin spacing:** the ineffective schPinSpacing prop was removed; supported per-pin margins are used. Schematic refinement remains possible without changing the routed copper.

## Other outstanding items

- **TOOL-003 — doctor registry configuration:** the earlier global npm authorization-header check failed while registry login/import/public source upload worked. No credentials or global configuration were changed. This is separate from circuit correctness.
- The tscircuit GitHub app previously returned repository_not_accessible (403). The two public repositories are published separately; no broader app access was granted.
- Assembly stock, exact passive/connector qualifications, CAD model alignment and filled/capped thermal-via processing remain unconfirmed.
- Current/thermal ratings, 3 V margin, regenerative transients and store qualification require bench evidence, as recorded in DESIGN_REVIEW.md and TEST_PLAN.md.

Sandboxed builds can show supplier-fetch warnings because network access is unavailable. Final build evidence is collected with network access; those warnings do not establish supplier unavailability. Native commands may exit successfully even when they report findings, so both logs and generated error records are reviewed.

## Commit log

2026-09-27 feat: initialize unrouted dual TT motor driver study
    [bom.csv]
2026-09-27 feat: define chassis mounting and publish unrouted review evidence
2026-09-27 Correct TT driver power path, thermal footprint, and pre-route checks
    [bom.csv]
2026-09-27 Apply working motor-board lessons to ground validation
2026-09-27 Route dual TT driver with verified ground and clearance checks
2026-09-27 Make routed board checks reproducible in tscircuit cloud
2026-09-27 Confirm public PCB viewer displays the routed board
2026-09-27 Expose the real order blockers with live stock and copper audits
    [B_Cu.gbr, B_Mask.gbr, B_Paste.gbr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]
2026-09-28 Fix motor-current copper and verify prototype assembly exports
    [jlc-smt-bom.csv, manual-tht-bom.csv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]
2026-09-28 Record verified alpha.5 publication and prototype handoff
2026-09-28 Rename DRV8833 dual TT motor driver repositories and package
2026-09-28 Add a verified hold-to-disable button for both motors
    [bom.csv, jlc-smt-bom.csv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]
2026-09-28 Refresh the order trace inventory for the disable button
    [trace-inventory.csv]
2026-09-28 Record the verified public button release
2026-09-29 Make every schematic sheet ready for design review
2026-09-29 Record verified alpha.7 schematic publication
2026-09-29 Add bottom evaluation label and verified fabrication artwork
    [B_SilkScreen.gbr]
